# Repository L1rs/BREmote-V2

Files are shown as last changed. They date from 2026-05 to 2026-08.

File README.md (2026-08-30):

# BREmote V2 — L1rs fork

A fork of **[Luddi96/BREmote-V2](https://github.com/Luddi96/BREmote-V2)**, the open source eFoil and Esk8 remote.

This page only describes what is **different here**. Everything else — the build video, mechanics, electronics, wiring examples, config tools and the original documentation — is unchanged and lives upstream:

> ### → [Luddi96/BREmote-V2](https://github.com/Luddi96/BREmote-V2)
> Start there if you want to build a BREmote. Come back here for the additions below.

The hardware is untouched. Both boards still run an ESP32-C3 with an SX1262 (Heltec HT-CT62) and the same 4 MB flash layout, so you can move between this firmware and Luddi96's at any time.

---

## What this fork adds

**Maintenance over WiFi.** The receiver is screwed into the hull, and getting a USB cable to it for every setting change is a nuisance. Both boards now open a small web page on your home network that gives you the same serial console you get over USB — every `?` command, including reading and writing the configuration — plus a firmware upload. See [WiFi maintenance](#wifi-maintenance) below.

**KISS ESC telemetry.** The receiver can read battery voltage and temperature from a BLHeli_32 or AM32 ESC, so you get a battery gauge without a VESC. Same connector, no hardware change. See [KISS ESC telemetry](#kiss-esc-telemetry).

**Info pages on the remote display.** With steering switched off, the toggle cycles the display through speed, board battery and ESC temperature. See [Info pages](#info-pages-on-the-remote-display).

If you are going to build this yourself, read [Building: RadioLib from git](#building-radiolib-from-git) first. It is not optional, and the failure mode is nasty.

---

## Firmware

| File | Board |
|---|---|
| `Source/V2.2.7.1-L1rs1_Integration_Rx.ino.bin` | Receiver, app only |
| `Source/V2.2.7.1-L1rs1_Integration_Rx.ino.merged.bin` | Receiver, full image |
| `Source/V2.2.7.2-L1rs1_Integration_Tx.ino.bin` | Remote, app only |
| `Source/V2.2.7.2-L1rs1_Integration_Tx.ino.merged.bin` | Remote, full image |

Built with the Arduino IDE, esp32 core 3.3.11, **RadioLib from git master** (see below), board *ESP32C3 Dev Module*, partition scheme *Default 4MB with spiffs (1.2MB APP/1.5MB SPIFFS)*. That is the same layout Luddi96 uses, so your stored configuration and pairing survive an update.

For a first flash over USB use the `merged.bin` with the [Espressif Flash Download Tool](https://dl.espressif.com/public/flash_download_tool.zip) at address `0x0`. **This erases the configuration**, so you will have to calibrate and pair again. To keep your settings, flash the plain `.ino.bin` to `0x10000` instead, or use the Arduino IDE.

Once WiFi is set up, updates go through the browser and you never need the cable again.

Upstream binaries are in [Luddi96's repository](https://github.com/Luddi96/BREmote-V2/tree/main/Source) if you want to go back.

---

## WiFi maintenance

### What you get

Open `http://<address of the board>/` in a browser and you get a terminal that behaves exactly like the USB console. Every command works there, including:

- `?conf` to read the configuration as a base64 string
- `?setConf:<string>` to write it back, so [Luddi96's config tool](https://lbre.de/BREmote/struct.html) still does the editing — you just copy the string in and out through the browser instead of a cable
- `?setBC:` for the battery curve, `?printGPS`, `?printRSSI`, `?printKiss` and everything else
- `/update` takes a firmware `.bin`

### When WiFi is on

WiFi never runs while you are riding. That is deliberate, and there is no setting to change it.

**Receiver:** joins the network at boot and switches WiFi off the moment the remote sends its first packet. It stays off until the next power cycle. So to reach it, **power the receiver up with the remote switched off** — on the foil battery or on a USB cable, whichever is easier.

**Remote:** joins the network while it sits on the charger, and in USB mode (hold throttle and toggle left while switching on). Both mean it is on a cable and not in use. Leaving the charge screen switches WiFi off again.

### One-time setup over USB

The credentials have to get onto the board once, and that has to happen over the cable. Connect the board over USB and open a serial terminal at 115200 baud — the Serial Monitor in the Arduino IDE does fine, as does [Luddi96's serial terminal](https://lbre.de/BREmote/sertest.html) in Chrome or Edge. Then send:

```
?setWifi:MyNetwork,mywifipassword,mymaintenancepassword
```

and afterwards:

```
?reboot
```

Three things about that command:

**The third field is a password you invent.** There is no default. It is not your WiFi password and it is not anything that already exists — you make it up here, and from then on it protects the web page and the firmware upload. Since the receiver drives a motor, do not reuse a password you use elsewhere. It is stored in plain text on the board.

**No commas in the SSID or in the maintenance password.** The command is split at the first and the last comma. Your WiFi password may contain commas, because it sits between them.

**2.4 GHz only.** The ESP32-C3 has no 5 GHz radio. If your router uses separate names per band, use the 2.4 GHz one.

The credentials live in their own file (`/wifi.txt`) and not in the configuration struct, so adding them does not disturb your calibration or pairing, and the config tool keeps working unchanged.

`?clearWifi` removes them again, `?printWifi` shows what is stored and whether the board is connected.

### Finding the board

**There is no mDNS**, so `bremote-rx-….local` will not resolve and neither will a ping to that name. It was left out on purpose: the mDNS library costs 40 KB of flash and the board is already at 90 %.

What the board does do is register its hostname with your router, as `bremote-rx-<MAC>` or `bremote-tx-<MAC>`. Look the address up in the router's device list once and give it a fixed one; then you can bookmark it.

The browser will ask for a user name and password: the user name is **`bremote`**, the password is the maintenance password from `?setWifi`.

### If it does not come up

`?printWifi` over USB tells you where it stopped. `Wifi: off` with an SSID stored usually means the receiver already saw the remote — switch the remote off and reboot. `connecting` that never finishes is almost always a wrong password or a 5 GHz-only network.

One trap worth knowing: the `?print…` commands run in a loop that only accepts `quit`. If a board seems to ignore everything you type, send `quit` first.

---

## KISS ESC telemetry

Set `data_src` to **3** and the receiver reads a BLHeli_32 or AM32 ESC instead of a VESC.

Wiring is the same as for a VESC: the ESC telemetry wire goes to **JP5**, the connector Luddi96 already documents for VESC UART. Nothing changes on the board, both run at 115200 baud through the same mux channel.

On the ESC side, **auto telemetry has to be enabled** in BLHeli Suite or the AM32 configurator. Without it the ESC only answers a DShot request and stays silent here.

Battery voltage and temperature go over the radio link and drive the usual battery and temperature bars. The frame also carries current, consumption and eRPM; those are read and shown by `?printKiss` but not transmitted, because adding fields to the telemetry packet would slow every other value down and break compatibility with boards running other firmware.

The battery percentage uses the same lookup table and load compensation as the analog and VESC paths, so `?setBC:` and the [LUT tools](https://lbre.de/BREmote/bat_conf.html) apply unchanged.

---

## Info pages on the remote display

`steer_enabled` gains a third value:

| Value | Meaning |
|---|---|
| 0 | Steering off (as before) |
| 1 | Steering on (as before) |
| 2 | Steering off, toggle switches display pages |

With `steer_enabled = 2`, **hold the toggle right** (throttle released) to step through:

| Page | Shows | Marker |
|---|---|---|
| 1 | Board battery in percent | `b` |
| 2 | ESC or VESC temperature in °C | `C` |
| 3 | Speed | `S` |

The battery comes first because that is the value you actually want at a glance, and until now it was only readable as the ten-step bar along the bottom edge. The speed page is the display every other `steer_enabled` setting shows.

The marker flashes up briefly when you switch, then the value appears. Gear changes with a short toggle press and locking with a long left press are unchanged.

The battery page is worth having on its own: until now that value was only visible as the ten-step bar along the bottom edge, which is hard to read precisely.

Note that `steer_enabled = 2` also releases the toggle when `no_gear` and `no_lock` are both set. In Luddi96's code that combination keeps the toggle permanently in steering, which would have made the pages unreachable.

---

## Building: RadioLib from git

**The RadioLib versions in the Arduino library manager will not work.** You need the current git master:

```bash
cd ~/Documents/Arduino/libraries
git clone https://github.com/jgromes/RadioLib.git
```

`startupRadio()` sets `radio.standbyXOSC = true` before `radio.begin()`, which keeps the oscillator running between packets so the turnaround from transmit to receive stays short. Up to and including RadioLib 7.7.1 that had two bugs: setting the flag before `begin()` made it fail with `-707`, and setting it afterwards silently did nothing, because `begin()` latches the Rx/Tx fallback mode and there was no way to change it later.

Both were fixed on 2026-07-04 ([jgromes/RadioLib#1827](https://github.com/jgromes/RadioLib/issues/1827), commit `88f38e9`), which also added `setStandbyXOSC()`. The last release, 7.7.1, is from 2026-05-31 and predates that, so the library manager still ships the broken version.

Symptoms if you get this wrong, in the order you will meet them:

`begin()` returns `-707` and the board sits in `while(1) blinkErr(...)`. **The serial console keeps answering**, because `blinkErr()` calls `checkSerial()` — so `?conf` works fine while the radio is dead and neither the PWM generation nor the radio tasks ever started. Do not judge a flash by whether the console responds; read the boot log and look for `Starting Radio ... Done`.

If you then "fix" it by moving the flag after `begin()`, the `-707` goes away and the receiver hears the remote perfectly, but the fallback mode stays at RC standby. The oscillator stops after every packet, the remote opens its receive window too late for the reply, and the link is one-way: the receiver acts on your throttle while the remote sits in failsafe. Ask me how I know.

Note that `BREmote_V2_Rx.h` and `_Tx.h` upstream still say `//V7.1.2` next to the include. That comment predates all of this.

## Serial commands added by this fork

| Command | Does |
|---|---|
| `?setWifi:<ssid>,<wifi pw>,<maintenance pw>` | Store WiFi credentials, reboot to apply |
| `?clearWifi` | Remove them again |
| `?printWifi` | SSID, hostname, connection state and IP |
| `?printKiss` | ESC telemetry until you send `quit` (receiver only) |

`?setConf:` also gained a safety check: a string of the wrong length or the wrong config version is now rejected instead of written. A garbled paste used to cost the pairing, which is expensive on a receiver you cannot reach.

Everything else works as upstream. Send `?` for the full list.

---

## Status codes and everything else

Unchanged from upstream. The [original README](https://github.com/Luddi96/BREmote-V2#statuserror-codes) has the status and error codes, the startup button combinations, the connection examples for VESC and ESC wiring, and the links to the config tools.

---

## Changelog

### V2.2.7.x-L1rs1
* WiFi maintenance for receiver and remote: web terminal with all serial commands, plus firmware upload over the browser
* Remote joins the network while charging and in USB mode, receiver at boot until the remote connects
* KISS telemetry from BLHeli_32 and AM32 ESCs (`data_src` 3)
* Info pages on the remote display (`steer_enabled` 2)
* Document that RadioLib from git master is required, and what breaks without it
* `?setConf:` rejects a configuration of the wrong size or version instead of writing it

---

## Credits

All of this builds on **[Luddi96](https://github.com/Luddi96)**'s work — the hardware, the mechanics and the firmware this fork changes a small part of. The web terminal served by the boards is a fork of his [serial terminal](https://lbre.de/BREmote/sertest.html), with the Web Serial API swapped for `fetch()` so it can talk over the network; the markup and styling are his.

Licence: GPL-3.0, as upstream. Logo uses "watersport" and "Skate" by Adrien Coquet from https://thenounproject.com/. CC BY 3.0.

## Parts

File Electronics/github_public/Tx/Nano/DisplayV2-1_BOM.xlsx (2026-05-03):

Comment | Designator | Footprint | JLCPCB Part #（optional）
100n | C1 | C0603
1u | C2 | C0603
HT16K33A-24SSOP | U$1 | HT16K33A | C5444736 | alt C5444738
np | R1 | R0603

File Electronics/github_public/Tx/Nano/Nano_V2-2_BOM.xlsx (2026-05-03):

Comment | Designator | Footprint | JLCPCB Part #（optional）
100 | R4 | R-EU_R0603
100n | C2, C3, C4, C5, C6, C9, C10, C13, C14, C15, C17, C20 | C-EUC0603
10k | R10, R11, R13, R14, R15, R16, R17, R22 | R-EU_R0603
10n | C12 | C-EUC0603
10u | C7, C8, C16 | C-EUC0603
0R | L_ANT | R-EU_R0402 | C17168 | Alt xC86128
1k | R3, R7, R12, R20, R21 | R-EU_R0603
np | C_ANT | C-EUC0402 | np | Alt xC285068
1u | C1, C18, C19 | C-EUC0603
2.2uF | C11 | C-EUC0603
3k3 | R6, R18 | R-EU_R0603
4k7 | R5, R8, R9 | R-EU_R0603
LQW15AN6N8G00D | L_ANT1 | R-EU_R0402 | C82919
6k8 | R19 | R-EU_R0603
74LVC1G14GW,125 | IC3 | 74LVC1G14GW,125 | C265125
ADS1115IDGSR | IC5 | ADS1115IDGSR | C37593
AO3400A | Q2, Q3, Q4, Q5 | AO3400A | C20917
AO3401A | Q6 | AO3401A | C15127
AW9523BTQR | IC10 | AW9523BTQR | C148077
CH340K | AC1 | CH340K | C968586 | alt C18208922
DW01A | IC4 | DW01A-G | C2927799 | alt C18164398 or C351410
FS8205A | Q1 | FS8205A | C2830320
ME6211C33M5G-N | IC6 | ME6211C50M5G | C82942
OH49E-S | IC1 | DRV5055A3QDBZR | C85573
RFANT3216120A5T | R2 | R-EU_R1206 | C127629
SDFL2012Q2R7KTF | L1, L2 | SDFL2012Q2R7KTF | C1046
TP4056 | IC7 | TP4056-42-ESOP8 | C725790
UHE4913G-AE3-R | IC2 | DRV5055A3QDBZR | C86815

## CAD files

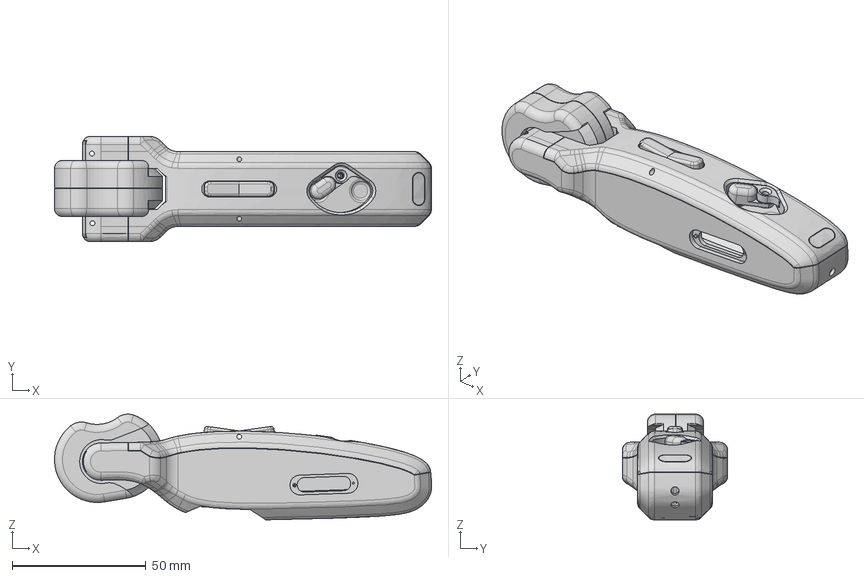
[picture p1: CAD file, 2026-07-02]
Mechanics/V2_Nano/V2_Nano.step
141.0 x 39.4 x 39.5 mm
Komponente1
V2.5_XX_Switch_Cover v1
Switch_Side v11
TX07 x 2

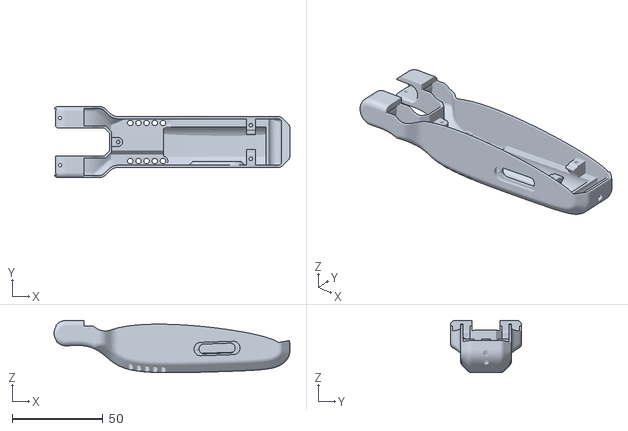
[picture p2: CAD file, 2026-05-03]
Mechanics/V2_Nano/Body_LED.stl
130.2 x 39.4 x 28.9

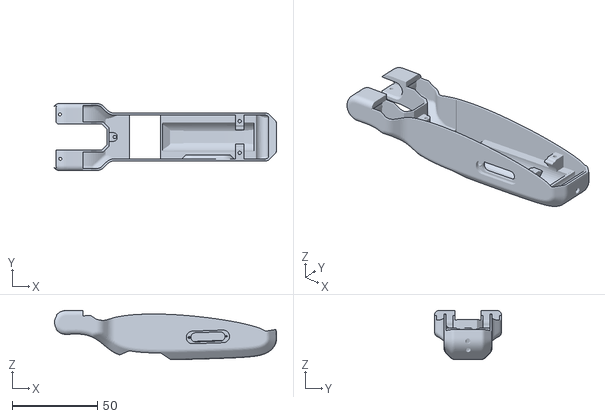
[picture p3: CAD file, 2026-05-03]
Mechanics/V2_Nano/Body_Display.stl
130.2 x 39.4 x 28.9

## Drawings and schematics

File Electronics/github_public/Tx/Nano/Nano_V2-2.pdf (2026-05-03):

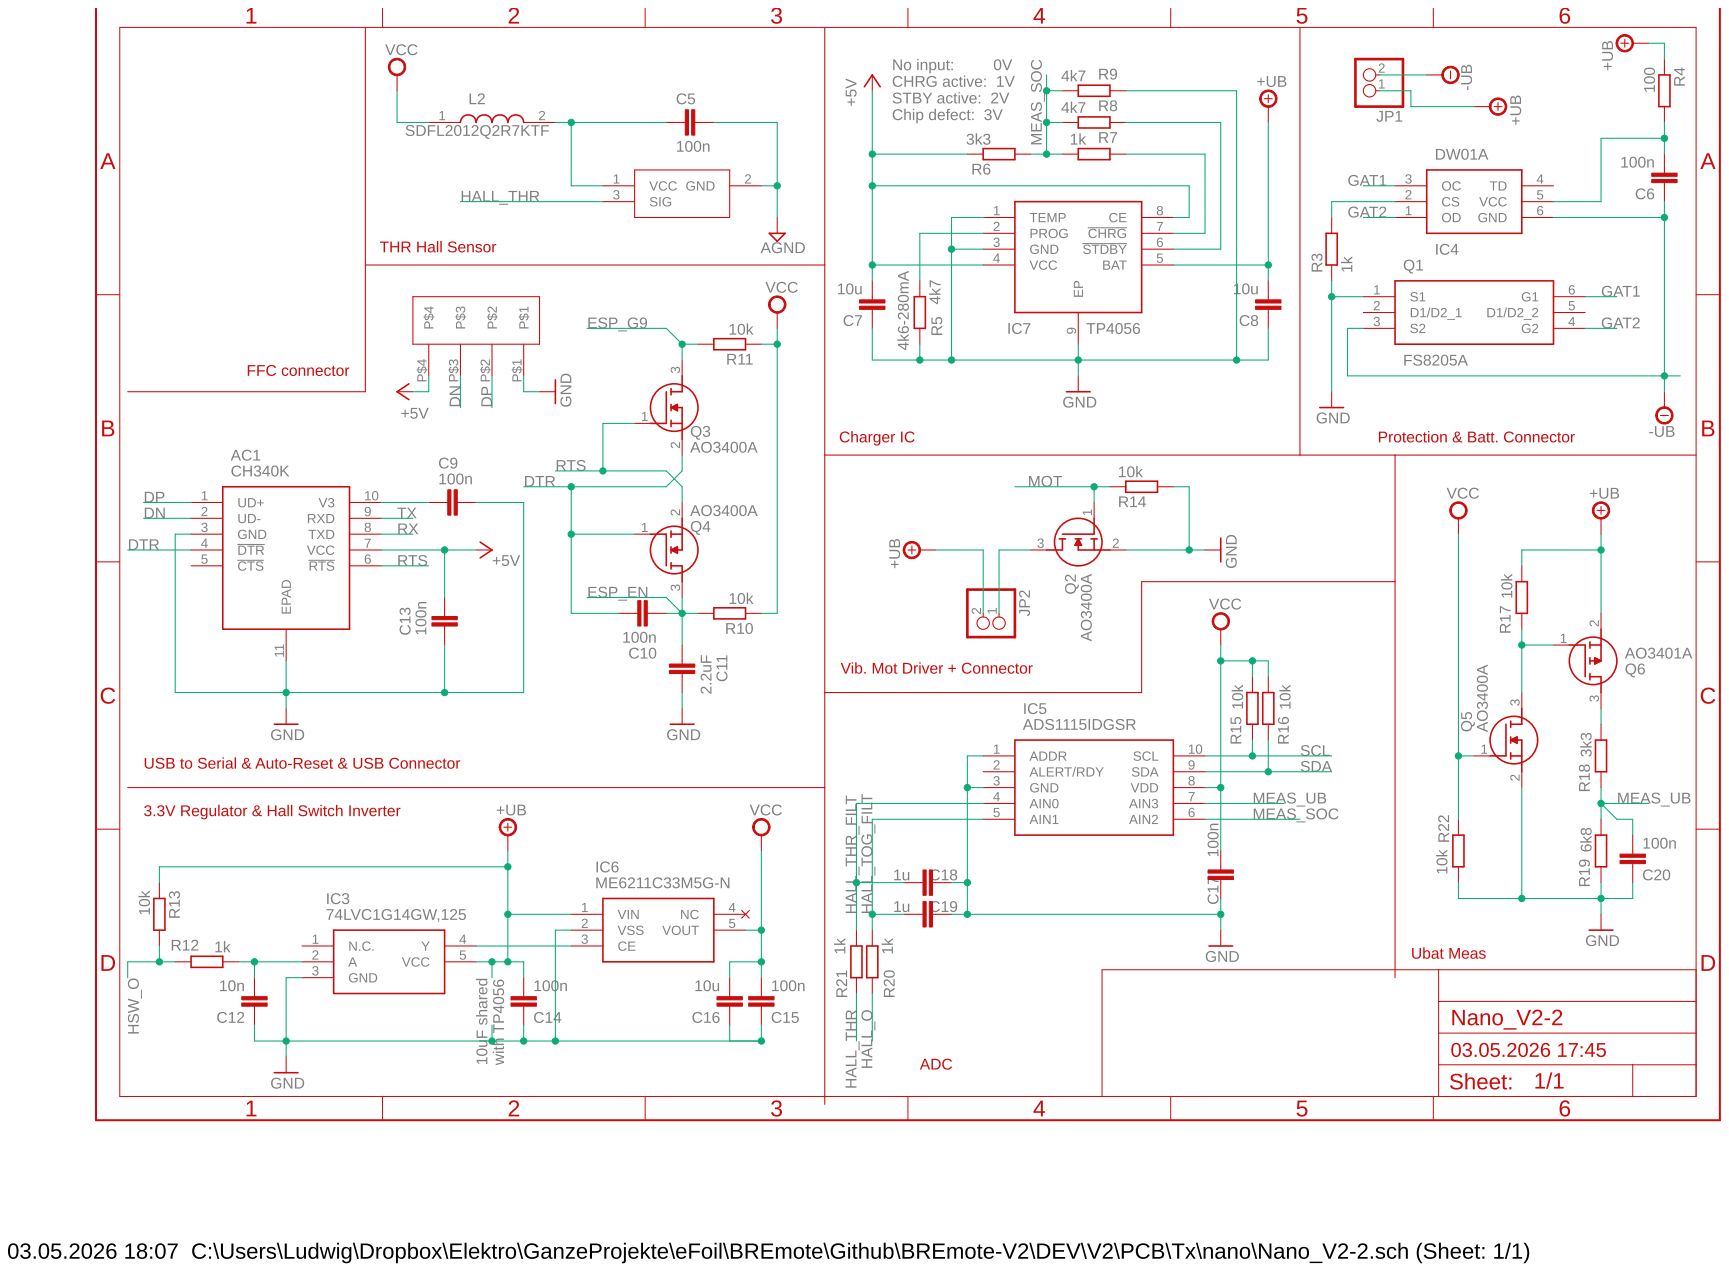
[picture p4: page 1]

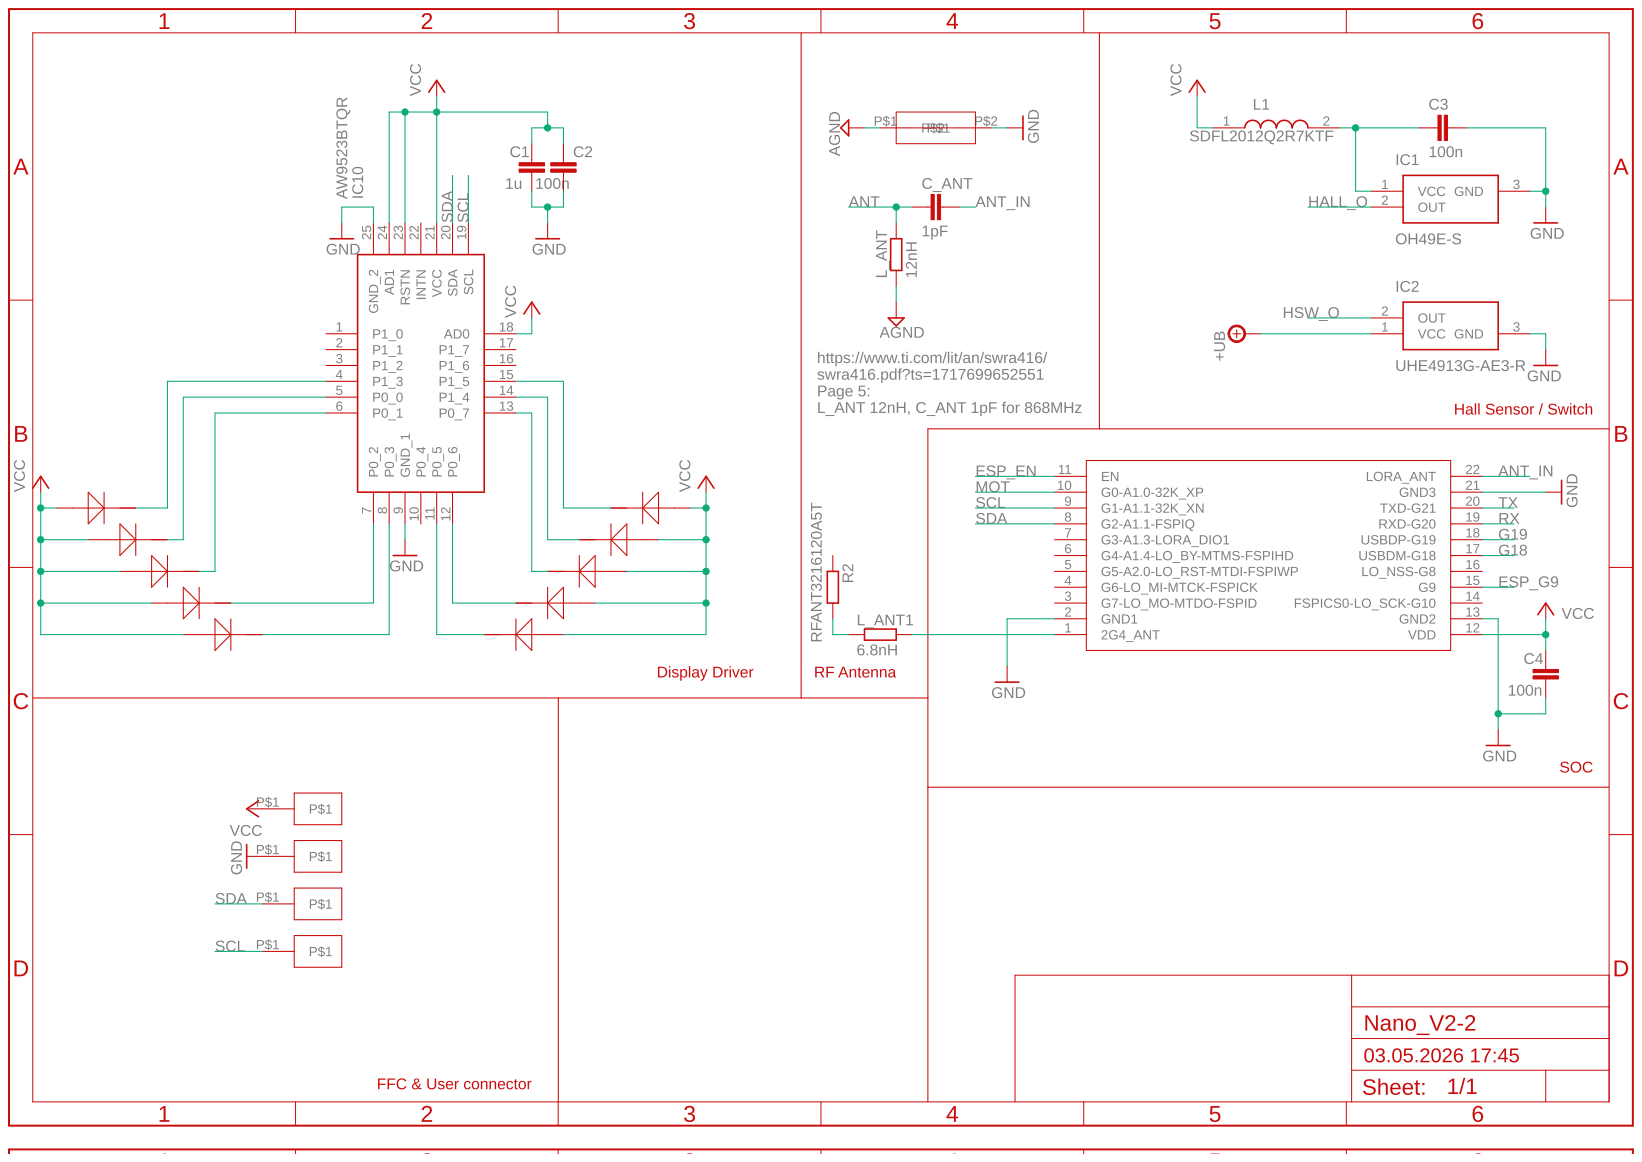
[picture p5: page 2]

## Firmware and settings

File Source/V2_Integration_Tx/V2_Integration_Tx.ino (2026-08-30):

#include "BREmote_V2_Tx.h"

SX1262 radio = new Module(P_LORA_NSS, P_LORA_DIO, P_LORA_RST, P_LORA_BUSY);
Adafruit_ADS1115 ads;
Ticker ticksrc;
WebServer server(80);

void setup()
{
  in_setup = true;
  enterSetup();

  Wire.begin(P_I2C_SDA, P_I2C_SCL); //SDA, SCL
  Wire.setClock(400000); // Set to 400 kHz
  startupDisplay();

  initSPIFFS();
  getConfFromSPIFFS();

  if(usrConf.max_gears <= 0) usrConf.max_gears = 1;

  startupADS();

  checkCharger();

  startupRadio();
  radio.setDio1Action(packetReceived);

  //Triggered by senData, waits from telem from Rx after sending data to it
  xTaskCreatePinnedToCore(waitForTelemetry, "wait_for_telem_triggered", 2048, NULL, 4, &triggeredWaitForTelemetryHandle, 0);
  //Runs every 100ms and sends data to Rx, medium prio
  xTaskCreatePinnedToCore(sendData, "Send_Data_100ms", 2048, NULL, 5, &sendDataHandle, 0);
  //Measure, Buffer and calculate inputs
  xTaskCreatePinnedToCore(measBufCalc, "meas_buf_calc_10ms", 2048, NULL, 6, &measBufCalcHandle, 0);
  //Update bargraphs
  xTaskCreatePinnedToCore(updateBargraphs, "update_bargraphs_200ms", 2048, NULL, 6, &updateBargraphsHandle, 0);
  //Vib motor
  xTaskCreatePinnedToCore(vibrationMotor, "vibration_motor_100ms", 2048, NULL, 6, &vibrationMotorHandle, 0);

  //Show boot animation and display internal battery voltage (needed for buffers)
  bootAnimation();
  //Check if calibration is valid, otherwise calibrate
  checkCal();
  //Check if a button combination is input
  checkStartupButtons();
  //Check if system is paired
  checkPairing();

  if(usrConf.no_lock)
  {
    while(thr_scaled > 10)
    {
      advanceArrow();
      delay(100);
    }
    system_locked = 0;
  }

  if(usrConf.no_gear)
  {
    gear = usrConf.max_gears-1;
  }
  else
  {
    if(usrConf.startgear >= usrConf.max_gears) usrConf.startgear = usrConf.max_gears-1;
    gear = usrConf.startgear;
  }

  exitSetup();
  in_setup = false;

  delay(100);
  if(serialOff)
  {
    Serial.end();
    digitalWrite(20, LOW); pinMode(20, OUTPUT);
    digitalWrite(21, LOW); pinMode(21, OUTPUT);
    digitalWrite(9, LOW); pinMode(9, OUTPUT);
  }
}

void loop()
{
  runMenu();
  if(in_menu > 0) in_menu--;

  checkSerial();

  if(millis() - last_packet > 300000)
  {
    deepSleep();
  }

  if(remote_error == 0)
  {
    if(system_locked)
    {
      displayLock();
    }
    else
    {
      //With steering off the toggle cycles these pages, board battery first.
      //The last page falls through to the speed display below, which is also
      //what every other steer_enabled setting shows.
      if(usrConf.steer_enabled == 2 && display_page == 0)
      {
        displayValue(telemetry.foil_bat);
      }
      else if(usrConf.steer_enabled == 2 && display_page == 1)
      {
        displayValue(telemetry.foil_temp);
      }
      else if(usrConf.speed_src != 4)
      {
        if(telemetry.foil_speed != 0xFF)
        {
          displayDigits(telemetry.foil_speed/10,telemetry.foil_speed-10*(telemetry.foil_speed/10));
        }
        else
        {
          displayDigits(DASH, DASH);
        }
      }
      else
      {
        uint8_t bat_pct = constrain(telemetry.foil_bat,0,99);
        displayDigits(bat_pct/10,bat_pct-10*(bat_pct/10));
      }
      updateDisplay();
    }
  }
  else
  {
    displayDigits(LET_E, remote_error);
  }
  
  delay(110);
  
} //End of loop()

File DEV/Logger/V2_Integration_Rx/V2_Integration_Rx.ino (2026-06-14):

#include "BREmote_V2_Rx.h"

SX1262 radio = new Module(P_LORA_NSS, P_LORA_DIO, P_LORA_RST, P_LORA_BUSY);
Adafruit_AW9523 aw;
Ticker ticksrc;
WebServer server(80);

void setup()
{
  enterSetup();

  Serial.print("Reset reason: ");
  Serial.println(esp_reset_reason());

  Wire.begin(P_I2C_SDA, P_I2C_SCL); //SDA, SCL
  Wire.setClock(400000); // Set to 400 kHz
  startupAW();

  initSPIFFS();
  getConfFromSPIFFS();
  getBCFromSPIFFS();

  startupRadio();
  radio.setPacketReceivedAction(packetReceived);
  radio.implicitHeader(6);
  radio.startReceive();

  delay(100);

  checkButtons();
  if(usrConf.paired == 2) waitForPairing();

  initRMT();

  Serial1.begin(115200, SERIAL_8N1, P_U1_RX, P_U1_TX);

  gpsConfigure();

  safeAwWrite(AP_EN_PWM0, 1);
  safeAwWrite(AP_EN_PWM1, 1);

  triggerReceiveSemaphore = xSemaphoreCreateBinary();
  loopTaskHandle = xTaskGetCurrentTaskHandle();
  
  //Runs every 10ms to generate both PWM signals, high prio
  xTaskCreatePinnedToCore(generatePWM, "Generate_PWM_10ms", 2048, NULL, 10, &generatePWMHandle, 0);
  //Runs upon RF interrupt and reads packet & responds, medium-high prio
  xTaskCreatePinnedToCore(triggeredReceive, "RF_ReceiveTask_triggered", 2048, NULL, 5, &triggeredReceiveHandle, 0);

  //Checks if there is connection and blinks LED, low prio
  xTaskCreatePinnedToCore(checkConnStatus, "Check_conn_staus_200ms", 2048, NULL, 2, &checkConnStatusHandle, 0);

  rxIsrState = 1;

  initLogger();
  if(usrConf.debug_byte & 1<<3)
  {
    Serial.println("Lograte 0.1Hz");
    setLogRate(0.1);
  }
  if(usrConf.debug_byte & 1<<4 && usrConf.gps_en)
  {
    Serial.println("Autostart logging");
    startLog();
  }

  exitSetup();
  PWM_active = 1;
}

unsigned long loop_timer = 0;
int wetness_counter = 0;

void loop()
{
  checkSerial();

  if(millis()-last_packet > 500 && millis() - radioBufferResetTimeout > 5000)
  {
    rxprintln("Emergency Radio Buffer Reset!");
    radioBufferResetTimeout = millis();
    radio.startReceive();
    rfInterrupt = false;
  }

  if(millis()-loop_timer > 1000)
  {
    loop_timer = millis();
    if(usrConf.wet_det_active)
    {
      wetness_counter++;
      if(wetness_counter >= 10)
      {
        checkWetness();
        wetness_counter = 0;
      }
    }
    if(usrConf.bms_det_active)
    {
      if(!safeAwRead(AP_BMS_MEAS))
      {
        if(telemetry.error_code == 0)
        {
        telemetry.error_code = 8;
        }
      }
      else
      {
        if(telemetry.error_code == 8)
        {
        telemetry.error_code = 0;
        }
      }
    }

    if(usrConf.data_src == 1)
    {
      getUbatLoop();
    }
    else if(usrConf.data_src == 2)
    {
      getVescLoop();
    }

    if(usrConf.gps_en)
    {
      //Delays 300ms non-blocking
      gpsPoll();
    }
  }

  bool shouldEnable = (millis() - last_packet > 10000);

  if (shouldEnable && !webUiEnabled) {
    enableWebUi();
  } else if (!shouldEnable && webUiEnabled) {
    disableWebUi();
  }

  if (webUiEnabled) {
    server.handleClient();
  }

  vTaskDelay(pdMS_TO_TICKS(10));
}

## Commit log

2026-05-03 Logger Bugfix, V2-Nano PCB added
    [DisplayShieldV2.sch, DisplayV2-1_BOM.xlsx, Nano_V2-2.sch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]
2026-05-03 Add Nano Body with Display cutout
    [Body_Display.stl, Body_LED.stl]
2026-06-14 Rx: I2C Mutex, Tx: CAL adaption for Nano
2026-07-01 Add vibration and bat% display
    [BREmote_V2_Tx.h, System.ino, V2_Integration_Tx.ino]
2026-07-02 Add rf packet collision detection (up to 5~6 riders close together)
    [BREmote_V2_Rx.h, Radio.ino, System.ino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]
2026-07-04 RF optimization (RadioLib bug #1827)
    Note: Build with newest RadioLib code (Github directly)
    [Radio.ino, System.ino]
2026-07-11 Added col.det. to Rx, fixed vibration of Tx
    [Radio.ino, System.ino]
2026-08-29 Add WiFi maintenance, KISS ESC telemetry and Tx info pages
    The receiver is screwed into the hull, so getting a USB cable to it for
    every setting change is a nuisance. Both boards now serve the same serial
    console over the home network, plus a firmware upload.
    Radio init
    startupRadio() sets standbyXOSC before begin(), which is the wrong order:
    entering XOSC standby needs a running oscillator, but the TCXO is only
    powered by setTCXO(), which RadioLib calls afterwards. Whether the
    rejected command surfaces is a matter of code layout, so the original
    gets away with it while almost any addition makes begin() fail with -707.
    Running begin() in RC standby fixes that, but begin() also l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
    [BREmote_V2_Rx.h, BREmote_V2_Tx.h, Display.ino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]
2026-08-30 Use RadioLib from git instead of working around its bug
    The radio init workaround in the previous commit was wrong, and the
    explanation that came with it was wrong too.
    standbyXOSC before begin() is correct as Luddi96 wrote it. The -707 and
    the fallback mode that would not change afterwards were both bugs in
    RadioLib, fixed by jgromes on 2026-07-04 in 88f38e9 along with a new
    setStandbyXOSC(), after Luddi96 reported them in jgromes/RadioLib#1827.
    The last release, 7.7.1, predates that by a month and there has been no
    release since, so the library manager still ships the broken version.
    Building against 7.7.1 is what made this look like an application bug.
    So both Radio.ino files are byte-i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
    [BREmote_V2_Rx.h, BREmote_V2_Tx.h, Display.ino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]
